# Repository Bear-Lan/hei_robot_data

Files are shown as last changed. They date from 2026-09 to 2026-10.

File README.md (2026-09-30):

<h1 align="center">HEI ReBot Lift</h1>

<p align="center">
  HEI ReBot Lift
</p>

<p align="center">
  <a href="README.md"><b>English</b></a> <b>|</b>
  <a href="README_zh.md"><b>中文</b></a> <b>|</b>
  <a href="README_Fr.md"><b>français</b></a> <b>|</b>
  <a href="README_es.md"><b>Español</b></a>
</p>

<p align="center">
  <a href="https://github.com/lipengdong/hei-rebot-lift/stargazers">
    
  </a>
</p>

## 🚀 Overview

**HEI ReBot Lift** is a **dual-arm lifting mobile robot project for embodied AI learning, reproduction, and real-robot validation**. Its goal is to **lower the barrier to building real robot learning systems**. It follows the idea of **truly reproducible open source**: not only releasing code, but also organizing **hardware materials, wiring, deployment steps, the VR teleoperation pipeline, dataset recording, ACT/VLA training, and real-robot rollout workflows**, so builders can move from hardware assembly all the way to policy deployment. The robot consists of dual arms, a lift platform, a four-wheel O-type omnidirectional chassis, and three cameras. The software is built on LeRobot and covers MuJoCo/Pinocchio inverse kinematics, LeRobotDataset, imitation learning, and VLA policy deployment.

<p align="center">
  <b>🚀 Dual-Arm Mobile Manipulation</b> · <b>📖 Open Hardware + Software Stack</b> · <b>🤖 LeRobot Ready</b>
</p>

<p align="center">
  <a href="#-quick-setup">🚀 Quick Setup</a> ·
  <a href="#-hardware">🦾 Hardware</a> ·
  <a href="#-startup-flow">🎮 Simulation / Teleoperation</a> ·
  <a href="#-record-data">📷 Record Data</a> ·
  <a href="#-train-act">🧠 Train ACT</a> ·
  <a href="#-train-smolvla">✨ Train VLA</a>
</p>

## ✨ Features

<div align="center">

<table>
  <thead>
    <tr>
      <th align="center">Icon</th>
      <th align="center">Capability</th>
      <th align="center">Description</th>
    </tr>
  </thead>
  <tbody>
    <tr><td align="center">🦾</td><td align="center">Dual-arm manipulation</td><td align="center">Damiao dual arms and grippers for teleoperation, recording, and policy rollout</td></tr>
    <tr><td align="center">⬆️</td><td align="center">Lift platform</td><td align="center">Automatic homing on startup, with the upper limit defined as <code>height.pos = 0</code></td></tr>
    <tr><td align="center">⭕</td><td align="center">Omnidirectional base</td><td align="center">Four-wheel O-type omnidirectional chassis with <code>x/y/theta</code> velocity control</td></tr>
    <tr><td align="center">🎮</td><td align="center">Keyboard / VR control</td><td align="center">Control the complete MuJoCo robot by keyboard or VR; Telegrip + Pinocchio/CasADi provide the VR IK pipeline</td></tr>
    <tr><td align="center">📷</td><td align="center">Three-camera data</td><td align="center"><code>front</code>, <code>left_wrist</code>, and <code>right_wrist</code> visual inputs</td></tr>
    <tr><td align="center">🧠</td><td align="center">Imitation learning / VLA</td><td align="center">Record keyboard/VR simulation data, visualize LeRobotDataset episodes, train ACT/VLA policies, and run them in simulation or on hardware</td></tr>
  </tbody>
</table>

HEI ReBot Lift demo

</div>

## 🤝 Get Your Own Robot / Join the Community

If you want to reproduce your own **HEI ReBot Lift**, you can follow the hardware materials, BOM, wiring notes, and software deployment documents gradually organized in this project to source parts and build the robot yourself. We also welcome builders and researchers interested in dual-arm mobile manipulation, VR teleoperation, LeRobot data collection, ACT/VLA training, and real-robot deployment to exchange ideas with us.

If you want to **get your own robot faster**, or would like to collaborate on hardware reproduction, teaching labs, data collection, algorithm validation, or application deployment, feel free to contact us.

<p align="center">
  <b>WeChat community / collaboration:</b> <code>hgm159951</code> &nbsp;&nbsp;|&nbsp;&nbsp;
  <b>Email:</b> <a href="mailto:hgm159951@163.com">hgm159951@163.com</a>
</p>

Reproductions, discussions, issues, improvements, and real-robot test feedback are all welcome.

## 📁 Project Layout

```text
hei-rebot-lift/
├── README.md
├── README_zh.md
├── README_Fr.md
├── README_es.md
├── LICENSE
├── community/                    # Community notes and collaboration records
├── hardware/                     # Hardware BOM, wiring, device binding, mechanical materials
├── media/                        # Images, videos, and README assets
├── docs/                         # Deployment and usage documentation
└── software/
    └── lerobot-hei-rebot-lift/   # Runnable LeRobot-based software project
```

The runnable software lives in:

```text
software/lerobot-hei-rebot-lift/
```

Quick Setup starts at the repository root. For later sections, open a new
terminal at the repository root for each command block; each block includes its
own `cd`. Replace `192.168.31.127` with your robot IP. The headset connects to
the **computer IP**, not the robot IP. The software directory is:

```bash
cd software/lerobot-hei-rebot-lift
```

## 🖼️ Showcase

<p align="center">
  HEI ReBot Lift robot
</p>

## ⭐ Star History

<p align="center">
  <a href="https://www.star-history.com/?repos=lipengdong%2Fhei-rebot-lift&type=date&legend=top-left">
    HEI ReBot Lift Star History
  </a>
</p>

## 🗺️ Roadmap & Latest Status

We will continue improving HEI ReBot Lift across hardware materials, software interfaces, data collection workflows, and mainstream embodied AI policy integrations. The table below summarizes the current status and links to the related documentation.

| Module | Status | Current Progress | Related DOC |
| --- | --- | --- | --- |
| Robot body | ✅ First version completed | Dual arms, lift platform, and four-wheel O-type omnidirectional base are integrated and tested as a complete system | [Hardware](hardware/README.md) |
| Complete robot URDF | ✅ Completed | Full robot model includes the chassis, wheels, lift, dual arms, parallel grippers, and TCP frames for simulation and real-robot IK | [URDF Model](software/lerobot-hei-rebot-lift/examples/hei_rebot_lift/VR_mujoco_ik/mujoco_ik/model/HEI_robot_urdf/) |
| MuJoCo simulation testing | ✅ Completed | Keyboard and VR control of both arms, grippers, lift, and chassis have been tested; includes wheel animations, workspace projection, and stable-grasp pick-and-place demonstrations | [Simulation Guide](software/lerobot-hei-rebot-lift/examples/hei_rebot_lift/VR_mujoco_ik/README.md) |
| Simulation data and policy loop | ✅ Verified | Keyboard or VR demonstrations publish synchronized 18-D states/actions and three camera views for LeRobotDataset recording, visualization, ACT training, and MuJoCo policy rollout | [Dataset, Training & Inference Guide](software/lerobot-hei-rebot-lift/examples/hei_rebot_lift/VR_mujoco_ik/mujoco_ik/SIM_DATASET_WORKFLOW.md) |
| Damiao motor driver | ✅ First version completed | `damiao_u2can` is implemented for dual arms, grippers, chassis, and lift motor control | [Damiao U2CAN](software/lerobot-hei-rebot-lift/src/lerobot/motors/damiao_u2can/) |
| Lift platform | ✅ First version completed | Supports upper-limit homing on startup and `height.pos` position-target control | [Robot Driver](software/lerobot-hei-rebot-lift/src/lerobot/robots/hei_rebot_lift/README.md) · [Independent Lift Control](software/lerobot-hei-rebot-lift/examples/hei_rebot_lift/README.md#independent-lift-test) |
| Omnidirectional base | ✅ First version completed | Supports `x.vel`, `y.vel`, and `theta.vel` commands with basic acceleration smoothing | [Robot Driver](software/lerobot-hei-rebot-lift/src/lerobot/robots/hei_rebot_lift/README.md) · [Independent Chassis Control](software/lerobot-hei-rebot-lift/examples/hei_rebot_lift/README.md#independent-chassis-test) |
| Three-camera vision | ✅ First version completed | Supports `front`, `left_wrist`, and `right_wrist` OpenCV cameras with MJPG by default | [Robot Driver](software/lerobot-hei-rebot-lift/src/lerobot/robots/hei_rebot_lift/README.md) |
| VR + MuJoCo IK | ✅ First version completed | Telegrip + MuJoCo + Pinocchio/CasADi is connected to the real-robot control pipeline | [VR MuJoCo IK](software/lerobot-hei-rebot-lift/examples/hei_rebot_lift/VR_mujoco_ik/README.md) |
| LeRobot integration | ✅ First version completed | `hei_rebot_lift` robot/client/host is implemented with teleoperate, record, replay, evaluate, and rollout scripts | [Examples](software/lerobot-hei-rebot-lift/examples/hei_rebot_lift/README.md) |
| Real-robot data collection | ✅ First version completed | Supports LeRobotDataset recording, resume recording, visualization, and bad-episode cleanup | [Record Guide](software/lerobot-hei-rebot-lift/examples/hei_rebot_lift/README.md) |
| ACT training and rollout | ✅ Verified | Supports ACT training and real-robot rollout | [Examples](software/lerobot-hei-rebot-lift/examples/hei_rebot_lift/README.md) |
| SmolVLA / VLA | ✅ Initial support | Supports SmolVLA training and real-robot rollout entry points | [Examples](software/lerobot-hei-rebot-lift/examples/hei_rebot_lift/README.md) |
| Open hardware materials | ✅ Completed | Overall BOM, full robot STEP assembly, printed-part STL files, metal parts list, and STEP/DWG manufacturing files are available | [Hardware](hardware/README.md) |
| Community and reproduction | 🚧 Ongoing | WeChat group, email contact, and GitHub project entry are available | [Community](community/README.md) |
| Other mainstream VLA deployment reproduction | ⏳ Coming soon | Plan to reproduce and test more mainstream VLA policies for training, inference, and real-robot deployment on HEI ReBot Lift | Not completed |

## 🦾 Hardware

The hardware package now includes the overall BOM, full robot STEP assembly, 3D printed parts, and metal/CNC/sheet-metal manufacturing files.

| Resource | File / Directory | Description |
| --- | --- | --- |
| Hardware guide | [hardware/README.md](hardware/README.md) | Hardware directory index, reproduction order, and safety checklist |
| Overall BOM V1.1 | [hardware/HEI_ReBot_Lift_BOM.md](hardware/HEI_ReBot_Lift_BOM.md) / [xlsx](hardware/HEI_ReBot_Lift_BOM.xlsx) | Main purchasing and preparation checklist; verify current prices before purchase |
| Full robot assembly | [hardware/Hei_robot_lift.STEP](hardware/Hei_robot_lift.STEP) | Full STEP model for structure review and assembly reference |
| 3D printed parts | [hardware/3D_Printed_Parts/](hardware/3D_Printed_Parts/) | STL files for printed covers, brackets, lift, chassis, and camera-related parts |
| Metal body parts list | [hardware/Metal_Parts/HEI_Metal_Body_Parts_List.xlsx](hardware/Metal_Parts/HEI_Metal_Body_Parts_List.xlsx) | Metal/CNC/sheet-metal part list |
| Metal CAD files | [hardware/Metal_Parts/step/](hardware/Metal_Parts/step/) / [hardware/Metal_Parts/dwg/](hardware/Metal_Parts/dwg/) | STEP and DWG files for machining communication |

### Assembly and Debugging Tutorial

Scan the QR code for the HEI ReBot Lift assembly and debugging tutorial. Use it
together with the repository BOM, latest CAD files, and safety checklist.

<p align="center">
  <a href="media/hei-rebot-lift-assembly-debugging-tutorial.png">HEI ReBot Lift assembly and debugging tutorial QR code</a>
  <br>
  <em>Scan to open the assembly and debugging tutorial.</em>
</p>

```text
Dual arms: left and right arms with 7 Damiao motors each. Joints 1-3 use DM4340P, joints 4-6 and gripper use DM4310
Chassis: four-wheel O-type omnidirectional mobile base, using DM4310 wheel motors
Lift: lead-screw lift platform using a DM4310 motor. On startup, the upper limit is homed as height.pos = 0
Cameras: three OpenCV cameras: front, left_wrist, right_wrist
Communication: ZMQ between robot-side host and computer-side client
Teleoperation: VR headset and controllers. Telegrip captures VR data; MuJoCo + Pinocchio/CasADi compute IK
```

## 🧩 Software Modules

```text
software/lerobot-hei-rebot-lift/src/lerobot/robots/hei_rebot_lift/        Robot driver
software/lerobot-hei-rebot-lift/src/lerobot/motors/damiao_u2can/          Damiao U2CAN communication
software/lerobot-hei-rebot-lift/examples/hei_rebot_lift/                  Record, replay, evaluate, and rollout scripts
software/lerobot-hei-rebot-lift/examples/hei_rebot_lift/VR_mujoco_ik/     VR + MuJoCo + Pinocchio IK
```

## ⚡ Quick Setup

Both machines need this project's code, but their dependencies and roles differ.
**Start each subsection at the repository root on the specified machine. Do not
execute robot-side and computer-side steps consecutively on one machine.**

| Machine | Environment | Purpose |
| --- | --- | --- |
| Robot-side Jetson | `lerobot5` | Hardware drivers, serial binding, robot host; no VR/IK environment needed |
| Your computer: control/training | `lerobot5` | Teleoperation client, dataset recording/editing, visualization, training, policy inference |
| Your computer: VR/simulation | `hei-rebot-vr` | Telegrip, MuJoCo, Pinocchio/CasADi FK/IK |

### 1. Robot-Side Jetson Installation

**Run only on the robot.** Install the hardware extras without the computer-side
dataset visualization and training extras. This still includes the project's
base dependencies; it is not a standalone driver package without PyTorch.

```bash
cd software/lerobot-hei-rebot-lift
conda create -n lerobot5 python=3.12 -y
conda activate lerobot5
python -m pip install -e ".[hardware,pyzmq-dep]"
python -c "import serial, zmq, cv2; print('robot dependencies ok')"
```

If a working `lerobot5` environment already exists, skip creation and activate
it before installation. For Jetson PyTorch/torchvision platform or version
conflicts, account for the installed JetPack and this project's version
constraints. Do not copy desktop CUDA wheels or bypass all dependencies with
`--no-deps`.

Next, follow Device Mapping below, verify limit switches and cameras, then start
`hei-rebot-lift-host` using Startup Flow. Do not create `hei-rebot-vr` on the robot.

### 2. Your Computer: Control, Recording, and Training

**Run only on your computer.** This environment runs `teleoperate.py`,
`record.py`, training, replay, and policy inference; it does not directly open
the robot's motor serial ports.

```bash
cd software/lerobot-hei-rebot-lift
conda create -n lerobot5 python=3.12 -y
conda activate lerobot5
python -m pip install -e ".[core_scripts,training,pyzmq-dep]"
python -m pip show pyzmq rerun-sdk pynput datasets accelerate
```

This includes dataset recording/editing, Rerun visualization, keyboard input,
ZMQ, and general training dependencies. Install SmolVLA-specific dependencies
in its training section below. Skip creation if `lerobot5` already exists.

### 3. Your Computer: VR/MuJoCo IK

On your computer, **open another terminal at the repository root**. Telegrip and
MuJoCo IK share `hei-rebot-vr`; do not mix these dependencies into `lerobot5`.
Use the conda-forge versions in `environment.yml` for FK/IK; do not separately
install `pin` with pip.

```bash
cd software/lerobot-hei-rebot-lift/examples/hei_rebot_lift/VR_mujoco_ik
conda env create -f environment.yml
conda activate hei-rebot-vr
env -u LD_LIBRARY_PATH python -c "import pinocchio as pin; from pinocchio import casadi as cpin; print(pin.__version__); print('casadi binding ok')"
```

For an existing environment, replace creation with
`conda env update -n hei-rebot-vr -f environment.yml --prune`. Launch wrappers
activate it automatically. Test pure simulation before connecting real hardware;
see the [VR deployment guide](software/lerobot-hei-rebot-lift/examples/hei_rebot_lift/VR_mujoco_ik/README.md).

## 🔌 Device Mapping

Stable udev device names are used by default:

```text
/dev/hei_right_arm   Right arm U2CAN
/dev/hei_left_arm    Left arm U2CAN
/dev/hei_chassis     Chassis U2CAN
/dev/hei_lift        Lift motor U2CAN
/dev/hei_lift_io     Lift limit-switch serial port
```

### 1. Serial and Camera Discovery and Binding Wizard

Run [Port_Binding_Wizard.py](software/lerobot-hei-rebot-lift/examples/hei_rebot_lift/debug/Port_Binding_Wizard.py)
on the **robot-side Jetson**. It identifies serial adapters from responding motor
IDs and limit-switch IO frames, then previews each camera so the user can assign
front, left-wrist, right-wrist, or skip it. Missing cameras do not stop available
devices from being bound. It does not enable motors, write zeros, or command motion.

**Prepare the hardware:**

1. Stop `hei-rebot-lift-host` and all motor/serial debug programs so the ports are free.
2. Power down and support the arms before changing wiring. Temporarily disconnect **right-arm IDs 4-7**, leaving IDs 1-3 connected; keep the left arm fully connected on IDs 1-7.
3. Check chassis IDs 1-4, lift ID 1, and the lift limit-switch IO wiring. Power the four U2CAN boards, IO board, and motors needed for discovery.
4. Keep USB sockets unchanged throughout scanning and rule installation.

Set serial-port read/write permissions before running the Python wizard:

```bash
sudo chmod 666 /dev/ttyACM*
sudo chmod 666 /dev/ttyUSB*
```

Start the interactive wizard from the repository root:

```bash
cd software/lerobot-hei-rebot-lift
PYTHONPATH=src conda run --no-capture-output -n lerobot5 \
  python -u examples/hei_rebot_lift/debug/Port_Binding_Wizard.py
```

Review the scan, confirm the arm/chassis/lift/IO mapping, and choose whether to
install the system rules. The default output is
`examples/hei_rebot_lift/rules/99-nx-robot.rules`, with an existing-file backup.
Installation into `/etc/udev/rules.d/` requires `sudo`; the wizard reloads rules
and checks symlinks. Existing lidar and IMU rules are preserved; those devices
are not identified by this scan.

**Verify the bindings:**

```bash
ls -l /dev/hei_right_arm /dev/hei_left_arm /dev/hei_chassis /dev/hei_lift /dev/hei_lift_io
ls -l /dev/hei_front_camera /dev/hei_left_wrist_camera /dev/hei_right_wrist_camera
```

If a symlink is missing, reconnect that USB device to the same socket and check
again. After verification, power down, reconnect right-arm IDs 4-7, and power up
before independent hardware tests below. Rules follow physical USB topology: keep each adapter
in its original socket, and rebind after changing sockets or hubs.

For missing/ambiguous devices, busy ports, or invalid IO frames, check power,
USB/CAN wiring, motor IDs, competing processes, and the IO baud rate before
accepting any mapping. For permission errors, check serial access (usually the
`dialout` group). Use interactive mode for first deployment. `--yes --install`
skips camera preview and preserves existing camera rules; use `--skip-cameras`
when rebinding serial devices only.

### 2. After Binding: Arm Zeros and Independent Hardware Tests

**Run all tests on the robot-side Jetson; no VR or computer client is needed.**
Run one debug tool at a time with the host and other serial programs stopped.
Each block starts in a new terminal at the repository root. For keyboard tools,
activate `lerobot5` and run Python directly in an interactive terminal; allocate
a TTY for SSH (for example, `ssh -t USER@ROBOT_IP`). Dashboards refresh in place.
Keep the physical emergency stop reachable; software stop keys do not replace it.

#### 2.1 Position the Arm at Its Designed Mechanical Zero Before Writing

**Warning: `Arm_Zero_Status_Test.py` immediately disables and writes zeros to
all seven motors (IDs 1-7) on that arm. It has no confirmation or read-only mode.
Do not start it at an arbitrary pose or use it for routine status inspection.**
Support the arms before disabling motors, as they can fall under gravity.

Use the assembly design and joint-zero definitions in the
[complete URDF model](software/lerobot-hei-rebot-lift/examples/hei_rebot_lift/VR_mujoco_ik/mujoco_ik/model/HEI_robot_urdf/)
to position the arm at its mechanical zero, not the VR controller's default
working pose. The physical gripper zero is closed (`0 rad`); do not force it
against its stop. The script cannot verify the pose. If the designed zero is
unclear, check the assembly references before writing anything.

<p align="center">
  <a href="media/arm_zero.png">Designed mechanical zero posture of both arms</a>
  <br>
  <em>Designed mechanical zero posture reference. Verify each joint against the assembly design before writing zeros; this is not the VR working pose.</em>
</p>

Write the right-arm zeros:

```bash
cd software/lerobot-hei-rebot-lift
conda activate lerobot5
PYTHONPATH=src python -u examples/hei_rebot_lift/debug/Arm_Zero_Status_Test.py \
  --port /dev/hei_right_arm
```

Exit with `Ctrl+C`, correctly position the left arm, and then run:

```bash
cd software/lerobot-hei-rebot-lift
conda activate lerobot5
PYTHONPATH=src python -u examples/hei_rebot_lift/debug/Arm_Zero_Status_Test.py \
  --port /dev/hei_left_arm
```

The script keeps motors disabled after writing and refreshes
`POS/VEL/TORQUE/ERROR`. Verify all seven motors are connected and responding
before checking positions near zero. A displayed zero alone does not establish
connectivity or successful calibration. Interpret `ERROR` according to the motor
protocol; not every nonzero state is a fault. Exit after calibration; rewrite
zeros only when assembly or maintenance requires recalibration.

#### 2.2 Independent Chassis Test: Directions, Gears, and Wheel Feedback

Secure the chassis with wheels off the ground, clear of cables and people.
This tool connects only the chassis, not the arms, lift, or cameras.
**All four wheels move through chassis kinematics; this is not single-wheel jog.**

```bash
cd software/lerobot-hei-rebot-lift
conda activate lerobot5
PYTHONPATH=src python -u examples/hei_rebot_lift/debug/Chassis_Status_Test.py \
  --port /dev/hei_chassis
```

| Key | Function |
| --- | --- |
| `1 / 2 / 3` | Low / medium / high gear; begin with low gear `1` |
| `W / S` | Forward / backward |
| `A / D` | Strafe left / right |
| `Q / E` | Rotate left / right |
| `Space` | Software command for zero speed on all wheels |
| `X` or `Ctrl+C` | Exit and stop the chassis |

Hold or repeat a direction key to maintain motion; the default key watchdog
clears the request after `0.65 s` without another direction event. Test each
direction briefly while observing requested/reconstructed body velocity and
each wheel's target/measured angular velocity, position, torque, and state code.
Body velocities use driver command units, not directly measured meters/second.

| Motor ID | Wheel position | Dashboard label |
| --- | --- | --- |
| `1` | Right front | `RF` |
| `2` | Right rear | `RR` |
| `3` | Left rear | `LR` |
| `4` | Left front | `LF` |

Stop for a stationary wheel, incorrect mapping, missing feedback, or abnormal
shaking; check IDs, wiring, and configuration rather than increasing speed.
After the suspended test passes, verify physical directions at low gear in a
clear area. Single-wheel jogging needs a separate mode not provided by this
tool; never substitute the arm zero-writing script on the chassis port.

#### 2.3 Independent Lift Test: Homing, Height, and Limit IO

**Startup automatically homes upward.** Check both limit-switch connections and
clear the travel path first. Support structures that could fall when disabled
and keep the emergency stop ready. This tool reuses production lift logic and
opens only the lift motor and limit IO ports.

```bash
cd software/lerobot-hei-rebot-lift
conda activate lerobot5
PYTHONPATH=src python -u examples/hei_rebot_lift/debug/Lift_Status_Test.py \
  --motor-port /dev/hei_lift --io-port /dev/hei_lift_io --height-step-mm 2
```

| Key | Function |
| --- | --- |
| `I / K` | Raise / lower target height; this example changes it by `2 mm` per key event |
| `Space` | Stop and use current reported height as the hold target |
| `H` | Home upward again, only with a safe travel path |
| `X` or `Ctrl+C` | Exit, stop, and disable |

Upper-limit homing defines `0 mm`; downward heights are negative, within
`-800..0 mm`. Move down and up in small steps while checking current/target
height, error, measured speed, motor command speed, IO freshness, and limits.
Confirm the relevant IO state at a known limit. Stop for offline IO, both limits
active, or incorrect states; investigate before retrying rather than repeatedly
driving into end stops.

**Finish all independent tests and exit the debug tools** before the simulation
practice and real startup below. Never let a debug tool compete with the host
for a serial port.

### 3. Camera Mapping

Default cameras (verify actual devices on the **robot**, not your computer):

```text
front       /dev/hei_front_camera
left_wrist  /dev/hei_left_wrist_camera
right_wrist /dev/hei_right_wrist_camera
```

Find connected cameras:

```bash
cd software/lerobot-hei-rebot-lift
PYTHONPATH=src conda run --no-capture-output -n lerobot5 \
  lerobot-find-cameras opencv --opencv-fourcc MJPG --opencv-width 640 --opencv-height 480 --opencv-fps 30
```

### Stable Camera Mapping

The binding wizard above creates stable `/dev/hei_*_camera` symlinks, so camera
IDs normally require no further edits. Run the wizard again after moving a
camera to another physical USB socket.

To manually override a camera device ID or path, edit
`software/lerobot-hei-rebot-lift/src/lerobot/robots/hei_rebot_lift/config_hei_rebot_lift.py`,
then change the corresponding `index_or_path` in `hei_rebot_lift_cameras_config()`:

```python
def hei_rebot_lift_cameras_config() -> dict[str, CameraConfig]:
    return {
        "front": OpenCVCameraConfig(index_or_path="/dev/hei_front_camera", fps=30, width=640, height=480, fourcc="MJPG"),
        "left_wrist": OpenCVCameraConfig(index_or_path="/dev/hei_left_wrist_camera", fps=30, width=640, height=480, fourcc="MJPG"),
        "right_wrist": OpenCVCameraConfig(index_or_path="/dev/hei_right_wrist_camera", fps=30, width=640, height=480, fourcc="MJPG"),
    }
```

Keep the names `front`, `left_wrist`, and `right_wrist` unchanged: datasets,
policies, and clients use these keys. Do not edit `camera_opencv.py` or the VR
YAML for USB IDs. A separate client keeps the same camera keys and dimensions;
the robot host opens the physical USB devices.

## 🎮 Startup Flow

### Identify the Computer and Robot IPs First

The examples use your computer IP `192.168.31.245` and example robot IP
`192.168.31.127`. **If the robot address differs, replace robot addresses only;
do not replace the computer address used by the headset.**

| Address | Owner | Used for |
| --- | --- | --- |
| `192.168.31.245` | Your control computer running Telegrip and MuJoCo IK | Headset browser: `https://192.168.31.245:8443` |
| `192.168.31.127` | Robot Jetson running the host | Client: `--remote-ip 192.168.31.127`; VR camera endpoint: `tcp://192.168.31.127:6556` |
| `localhost` / `127.0.0.1` | The machine running that program, not the remote robot | Local VR, action, and feedback connections when Telegrip, MuJoCo IK, and the client share one computer |

Practice in pure simulation below before real control. Keyboard simulation only
needs the computer; VR simulation needs the computer and headset to communicate. For real control, also connect the
robot to the same mutually reachable LAN. **Run each block in a new terminal at
the repository root on the specified machine.** Keep long-running processes open.

### 1. Beginner Practice: Computer-Side Pure Simulation (No Hardware)

<p align="center">
  HEI ReBot Lift VR simulation in MuJoCo
</p>

Install `hei-rebot-vr` first. **Do not start the robot host, `teleoperate.py`,
`record.py`, or the real bridge during practice; stop them if already running.**
Pure simulation requires no motors, device bindings, or robot feedback and does
not publish real actions on `6558`.

#### 1.1 Practice by Keyboard Without a Headset

```bash
cd software/lerobot-hei-rebot-lift/examples/hei_rebot_lift/VR_mujoco_ik
./run_hei_robot_keyboard_sim.sh
```

Press `1/2/3/4` to select chassis, lift, left arm, or right arm. Chassis uses
`W/S`, `A/D`, and `Q/E`; lift uses `I/K`; arm TCP translation uses `W/S`,
`A/D`, and `R/F`, while rotation uses `U/J`, `I/K`, and `O/L`. Use `Z/X` to
open/close the selected gripper, and `5/6` to reset the left/right arm gradually. See the
[keyboard and VR simulation guide](software/lerobot-hei-rebot-lift/examples/hei_rebot_lift/VR_mujoco_ik/README.md)
for all controls and speed options.

#### 1.2 Computer VR Practice Terminal A: Start Telegrip

```bash
cd software/lerobot-hei-rebot-lift/examples/hei_rebot_lift/VR_mujoco_ik
./run_telegrip.sh
```

Connect the headset and computer to the same LAN. In the headset browser, open
`https://192.168.31.245:8443` (computer IP), verify the self-signed certificate
warning, and enter VR.

#### 1.3 Computer VR Practice Terminal B: Start the Complete Robot Simulation

```bash
cd software/lerobot-hei-rebot-lift/examples/hei_rebot_lift/VR_mujoco_ik
./run_hei_robot_vr_sim.sh
```

Observe the robot in the **MuJoCo window on your computer**. The scene includes
both arms, parallel grippers, lift, four-wheel omnidirectional chassis, a table,
cubes, and a banana for pick-and-place practice. Without a physical robot, no
real camera feed will appear in the headset; simulation still works.
`vr_images.enabled` is currently `false` in `telegrip/config.yaml`; leave it
disabled for practice. Changing it requires restarting Telegrip.

#### 1.4 Practice Controller Inputs in Order

<table align="center">
  <tr>
    <td align="center"><a href="media/META-QUEST-BUTTON.jpg">Meta Quest system button on the right controller</a><br><b>Meta Quest System Button</b></td>
    <td align="center"><a href="media/META-GRIP-BUTTON.jpg">Side grip button location</a><br><b>Grip: Side Button</b></td>
    <td align="center"><a href="media/META-FRONT-TRIGGER.jpg">Front trigger location</a><br><b>Trigger: Front Trigger</b></td>
  </tr>
</table>

Click an image to view it at full size.

> [!IMPORTANT]
> **Calibrate the VR origin before control: hold the right controller's META QUEST BUTTON for about 3 seconds to recenter using the headset's current position and heading as the VR reference origin for this session.**
> **Recalibrate after changing your standing/seated position or operating direction. If controller motion and arm motion point in different directions or directional tracking feels wrong, stop control and recalibrate before continuing.**
> Sequence: **release both `grip` buttons → center the sticks → face the intended forward direction from your new position → hold the Meta Quest button for about 3 seconds → let tracking settle and hold `grip` again**. Verify direction with a small movement first.

The Meta Quest button recenters the **headset/VR reference frame**; `grip`
captures each arm's relative control origin. These are different operations.
Neither writes motor zeros nor replaces lift homing. Follow the calibration
procedure for both simulated and real VR control.

| Exercise | Procedure |
| --- | --- |
| Single-arm translation and rotation | Hold that side's `grip` to capture a relative origin; make small XYZ translations and rotations while observing the TCP. Practice each arm separately |
| Release and recapture the origin | Release `grip` to stop tracking, reposition the controller comfortably, then hold it again; the arm need not follow the controller back to its origin |
| Gripper pick and place | Simulation grippers start closed; real startup restores measured state. While holding `grip`, press `trigger` to open and release it to close; close near an object for stable-grasp practice, then open to place it |
| Lift | Left `grip` + left stick vertical; releasing left `grip` stops the lift request |
| Chassis | Right `grip` + right stick for forward/backward and strafing; right `B` rotates clockwise, left `Y` counterclockwise; releasing right `grip` stops the request |
| Reset | With the corresponding `grip` released, right `A` / left `X` gradually resets that arm. Focus the computer's MuJoCo window and press `R` to reset the robot and objects, in pure simulation only |

Keep sticks centered when practicing arm motion to avoid unintended chassis or
lift movement. At joint/workspace boundaries, reduce motion and return to the
reachable area instead of pushing farther out. See the
[controller tutorial](software/lerobot-hei-rebot-lift/examples/hei_rebot_lift/VR_mujoco_ik/README.md)
for complete instructions.

#### 1.5 Collect, Train, and Run Policies in Simulation

The complete MuJoCo environment is also a reproducible policy-development
environment. Demonstrations can be controlled by **keyboard or VR**, recorded
with the same 18-D state/action schema and `front`, `left_wrist`, and
`right_wrist` camera keys used by the robot, then visualized, trained, and
played back through a policy in MuJoCo.

| Stage | MuJoCo process (`hei-rebot-vr`) | LeRobot process (`lerobot5`) |
| --- | --- | --- |
| Keyboard demonstration | `run_hei_robot_keyboard_dataset_sim.sh` | `run_hei_robot_keyboard_record.sh` |
| VR demonstration | Telegrip + `run_hei_robot_vr_dataset_sim.sh` | `run_hei_robot_mujoco_record.sh` |
| Dataset inspection | - | `lerobot-dataset-viz` or `inspect_mujoco_dataset.py` |
| Policy training | - | `lerobot-train` with ACT or another supported policy |
| Simulation inference | `run_hei_robot_policy_sim.sh` | `run_hei_robot_mujoco_rollout.sh` |

The ordinary `run_hei_robot_keyboard_sim.sh` and `run_hei_robot_vr_sim.sh`
commands are practice-only and do not publish dataset samples. Recording uses
the dedicated `*_dataset_sim.sh` server plus its recorder in a second terminal.
Keep the simulation and recording FPS equal.

Follow the **[MuJoCo Dataset, Training, and Inference Guide](software/lerobot-hei-rebot-lift/examples/hei_rebot_lift/VR_mujoco_ik/mujoco_ik/SIM_DATASET_WORKFLOW.md)**
for exact environment boundaries, launch commands, keyboard/VR recording,
episode visualization, ACT training, and policy rollout. This workflow never
connects to the physical robot unless you separately start the real-robot
programs.

#### 1.6 Move to Hardware Only After Practice

- Control each arm's translation/rotation and confidently release/recapture the relative origin with `grip`.
- Recenter with the Meta Quest button and know to recalibrate after moving, changing heading, or observing a direction mismatch.
- Complete a pick-and-place exercise and understand that gripper state persists after releasing `grip`.
- Control chassis/lift directions, stop their requests, and keep sticks centered.
- Distinguish simulation and real launch scripts, locate the emergency stop, and understand real workspace hazards.

Close the pure-simulation viewer or stop it with `Ctrl+C`, then follow sections
2 and 3 below. Telegrip may stay running. If camera streaming was disabled,
restore `vr_images.enabled: true`, check the robot camera IP, and restart
Telegrip when real camera display is needed; do not launch duplicate instances.
**Simulation practice does not replace hardware safety checks.** Stable grasping
is a kinematic demonstration, not contact-physics validation. Motor directions,
zeros, limits, and load capacity still require independent verification, and
simulation lift speed can differ from real hardware.

### 2. Robot-Side Jetson: Start the Host (Terminal 1)

Run only on the robot. Complete device mapping, clear the workspace, and keep
the emergency stop reachable. Startup moves the lift upward to home;
**wait for homing to finish** before proceeding. The host runs on the robot;
it does not need the computer IP and is not the computer-side client.

```bash
cd software/lerobot-hei-rebot-lift
PYTHONPATH=src conda run --no-capture-output -n lerobot5 hei-rebot-lift-host
```

Keep this robot terminal running. Do not start Telegrip or MuJoCo IK on Jetson.

### 3. Your Computer: Start the Control Programs

Run all three programs below on **your computer** at `192.168.31.245`, not on Jetson.

#### 3.1 Start Telegrip (Computer Terminal 2)

```bash
cd software/lerobot-hei-rebot-lift/examples/hei_rebot_lift/VR_mujoco_ik
./run_telegrip.sh
```

#### 3.2 Headset Browser: Open the Computer's Page

For example, if the computer running Telegrip has LAN IP `192.168.31.245`, enter
this address in the **VR headset browser**:

```text
https://192.168.31.245:8443
```

Connect the headset and computer to the same LAN and start `run_telegrip.sh`
before opening the page. Use the **computer IP, not the robot IP**, and use
`https`. On the first visit, verify that the address belongs to your computer
before continuing past the self-signed certificate warning, then enter VR using
the page controls.

VR camera display is currently disabled. To enable it, set
`vr_images.enabled: true` and
`vr_images.endpoint: tcp://192.168.31.127:6556` in the computer's
`software/lerobot-hei-rebot-lift/examples/hei_rebot_lift/VR_mujoco_ik/telegrip/config.yaml`.
This must use the **robot IP**. Restart Telegrip after editing it; the client's
`--remote-ip` does not update this configuration.

#### 3.3 Start the Teleoperation Client (Computer Terminal 3)

Set `--remote-ip` to the **robot Jetson IP**, not the computer's `192.168.31.245`.
The client supplies robot feedback and waits for MuJoCo IK actions:

```bash
cd software/lerobot-hei-rebot-lift
PYTHONPATH=src conda run --no-capture-output -n lerobot5 python -u examples/hei_rebot_lift/teleoperate.py --remote-ip 192.168.31.127
```

#### 3.4 Start the Complete-Model Real Bridge (Computer Terminal 4)

Run on the same computer as Telegrip and the client. Default internal
connections stay local; do not replace their addresses with the robot IP:

```bash
cd software/lerobot-hei-rebot-lift/examples/hei_rebot_lift/VR_mujoco_ik
./run_hei_robot_vr_real.sh --enable-real-publish
```

With fresh robot feedback and VR data, release both grip buttons together and
wait for `command bridge ARMED`. The flag acknowledges real command publishing;
it does not bypass synchronization. For simulation only, use
`./run_hei_robot_vr_sim.sh`; the legacy dual-arm entry is `./run_mujoco_ik.sh`.
See the [VR guide](software/lerobot-hei-rebot-lift/examples/hei_rebot_lift/VR_mujoco_ik/README.md)
for controller inputs, recovery, and lift visualization limitations.

Keep **one robot-side host and three computer-side programs** running. To record
data, replace `teleoperate.py` in computer terminal 3 with `record.py`; never run
both together.

## 📷 Record Data

Stop `teleoperate.py` first. `record.py` replaces it as the action receiver and
feedback publisher; never run both together. Keep the host and Telegrip running,
then release both grips to re-arm the bridge after feedback reconnects.

```bash
cd software/lerobot-hei-rebot-lift
PYTHONPATH=src conda run --no-capture-output -n lerobot5 python -u examples/hei_rebot_lift/record.py   --repo-id HGM/hei_rebot_lift_task1   --remote-ip 192.168.31.127   --num-episodes 5   --episode-time-sec 120   --reset-time-sec 30   --task-description "Pick up the yellow block from the floor and put it on the table in front"
```

By default, data is saved locally and is not pushed to the Hugging Face Hub. Add `--push-to-hub` when uploading is needed.

## 🧠 Train ACT

Train on your computer; no robot host or VR process is required. Use the actual
dataset path printed during recording. If you chose a custom `--root`, also pass
`--dataset.root=YOUR_DATASET_PATH`; the dataset ID must match. These short runs
are smoke tests, not a guarantee of a deployable policy.

```bash
cd software/lerobot-hei-rebot-lift
PYTHONPATH=src conda run --no-capture-output -n lerobot5 lerobot-train   --dataset.repo_id=HGM/hei_rebot_lift_task1   --policy.type=act   --policy.device=cuda   --policy.push_to_hub=false   --output_dir=outputs/train/act_hei_rebot_lift_task1   --job_name=act_hei_rebot_lift_task1   --batch_size=8   --steps=10000   --save_freq=10000   --log_freq=200   --num_workers=4   --wandb.enable=false
```

## ✨ Train SmolVLA

Install the policy-specific dependencies first (new terminal at repository root):

```bash
cd software/lerobot-hei-rebot-lift
conda run --no-capture-output -n lerobot5 python -m pip install -e ".[smolvla]"
```

The general `training` extra does not install every VLA policy's dependencies.

```bash
cd software/lerobot-hei-rebot-lift
PYTHONPATH=src conda run --no-capture-output -n lerobot5 lerobot-train   --dataset.repo_id=HGM/hei_rebot_lift_task1   --policy.type=smolvla   --policy.device=cuda   --policy.push_to_hub=false   --output_dir=outputs/train/smolvla_hei_rebot_lift_task1   --job_name=smolvla_hei_rebot_lift_task1   --batch_size=1   --steps=1000   --save_freq=1000   --log_freq=50   --num_workers=2   --wandb.enable=false
```

## 🤖 Real-Robot Rollout

Keep the robot host running, but stop VR command publishing and any teleoperation,
recording, or replay process first. Use only one robot command source. Confirm the
checkpoint exists and camera names match the training data; start with a clear
workspace and a short test.

ACT rollout:

```bash
cd software/lerobot-hei-rebot-lift
PYTHONPATH=src conda run --no-capture-output -n lerobot5 python -u examples/hei_rebot_lift/rollout.py   --remote-ip 192.168.31.127   --model-id outputs/train/act_hei_rebot_lift_task1/checkpoints/010000/pretrained_model   --task "Pick up the yellow block from the floor and put it on the table in front"   --duration-sec 30   --inference sync
```

SmolVLA rollout:

```bash
cd software/lerobot-hei-rebot-lift
PYTHONPATH=src conda run --no-capture-output -n lerobot5 python -u examples/hei_rebot_lift/rollout.py   --remote-ip 192.168.31.127   --model-id outputs/train/smolvla_hei_rebot_lift_task1/checkpoints/001000/pretrained_model   --task "Pick up the yellow block from the floor and put it on the table in front"   --duration-sec 60   --fps 10   --inference rtc
```

## 📖 More Documentation

- [Documentation index](docs/README.md)
- [Recording, resume, training, and rollout](software/lerobot-hei-rebot-lift/examples/hei_rebot_lift/README.md)
- [Robot configuration, lift units, and watchdog](software/lerobot-hei-rebot-lift/src/lerobot/robots/hei_rebot_lift/README.md)
- [VR deployment, controller tutorial, and self-checks](software/lerobot-hei-rebot-lift/examples/hei_rebot_lift/VR_mujoco_ik/README.md)

## 🙏 References & Acknowledgments

The development of HEI ReBot Lift benefits from several excellent open-source projects and community efforts. In particular, we would like to thank:

- **LeRobot**: for providing a unified robot interface, the LeRobotDataset format, training utilities, and policy implementations such as ACT and SmolVLA, which form a strong foundation for real-robot data collection, training, and deployment.
- **reBot / reBot-DevArm**: for open robotic arm hardware, model resources, and practical references for embodied AI open-source projects. It also inspired the way this project organizes hardware materials, deployment documentation, and reproducible workflows.

This project customizes and extends ideas from these open-source ecosystems, aiming to further lower the barrier to learning, reproducing, collecting data with, and deploying policies on a dual-arm lifting mobile robot.

## 📄 License

This project is built on top of Hugging Face LeRobot and keeps the LeRobot dataset, training, policy, and robot-interface ecosystem. Please also follow the original LeRobot license requirements.

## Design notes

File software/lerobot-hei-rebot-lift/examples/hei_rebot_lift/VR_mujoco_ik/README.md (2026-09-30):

# HEI ReBot Lift VR + MuJoCo IK

[English](README.md) | [中文](README_zh.md)

This directory contains the complete VR teleoperation pipeline:

- `telegrip/`: starts the HTTPS/WebXR page, receives VR headset/controller data, and publishes it through ZMQ at `tcp://*:5567`.
- `mujoco_ik/`: receives Telegrip VR data, visualizes the complete robot model (or the legacy dual-arm model) in MuJoCo, solves FK/IK with Pinocchio + CasADi, and publishes LeRobot-compatible actions to `tcp://*:6558`.
- `examples/hei_rebot_lift/vr_control.py`: receives those actions and publishes lightweight real-robot joint/lift feedback on `tcp://*:6559` for safe startup synchronization.
- `mujoco_ik/hei_robot_vr_mujoco_sim.py`: controls the complete robot model in pure simulation. It never publishes commands to the real robot.
- `mujoco_ik/hei_robot_keyboard_mujoco_sim.py`: controls the complete model by keyboard without VR or real-robot commands.
- `examples/hei_rebot_lift/record.py`: subscribes to `tcp://localhost:6558` and saves robot actions/observations into a LeRobotDataset.

## Layout

```text
VR_mujoco_ik/
  environment.yml          # Unified conda environment for Telegrip + MuJoCo IK
  run_telegrip.sh          # Start the VR Web page and VR data publisher
  run_mujoco_ik.sh         # Existing dual-arm real-robot action pipeline
  run_hei_robot_keyboard_sim.sh # Complete robot, keyboard-controlled pure simulation
  run_hei_robot_vr_sim.sh  # Complete robot, VR-controlled pure simulation
  run_hei_robot_vr_real.sh # Complete model + real-robot command bridge
  telegrip/                # WebXR/HTTPS/WebSocket/ZMQ VR bridge
  mujoco_ik/               # MuJoCo model, IK main program, Pinocchio tools
```

## Environment Setup

Each block beginning with `cd examples/...` starts in a new terminal at
`software/lerobot-hei-rebot-lift/`. Commands without `cd` assume you are already
in `VR_mujoco_ik/`. The wrappers activate `hei-rebot-vr` automatically; direct
Python commands need explicit activation. The LeRobot client uses a separate
`lerobot5` environment.

Use one shared conda environment instead of separate `VR_Telegrip` and `mujoco_vr` environments.

```bash
cd examples/hei_rebot_lift/VR_mujoco_ik
conda env create -f environment.yml
```

Update an existing environment:

```bash
conda env update -n hei-rebot-vr -f environment.yml --prune
```

Verify Pinocchio + CasADi:

```bash
conda activate hei-rebot-vr
env -u LD_LIBRARY_PATH python -c "import pinocchio as pin; from pinocchio import casadi as cpin; print(pin.__version__); print('casadi binding ok')"
```

## Startup Flow

### 1. Practice With Keyboard Simulation

Keyboard mode does not require Telegrip and never publishes real-robot commands:

```bash
cd examples/hei_rebot_lift/VR_mujoco_ik
./run_hei_robot_keyboard_sim.sh
```

Mode keys prevent conflicts between chassis, lift, and arm controls. Hold a
motion key for continuous movement and release it to stop. TCP translation and
rotation use the fixed robot frame: `+X` forward, `+Y` left, and `+Z` up.

| Mode/key | Function |
| --- | --- |
| `1` | Chassis mode |
| Chassis `W/S`, `A/D`, `Q/E` | Forward/back, strafe left/right, rotate left/right |
| `2` | Lift mode |
| Lift `I/K` | Raise/lower |
| `3` / `4` | Select left/right arm TCP control |
| `5` / `6` | Reset the left/right arm gradually; press once, or move that arm to cancel |
| Arm `W/S`, `A/D`, `R/F` | Translate TCP along positive/negative `X/Y/Z` |
| Arm `U/J`, `I/K`, `O/L` | Rotate TCP about positive/negative `Rx/Ry/Rz` |
| Arm `Z/X` | Open/close the selected gripper with stable scene grasping |
| `Shift` | Fine control at 25% of normal speed by default |
| `Space` | Clear chassis velocity immediately and hold both arms |
| `V` / `Backspace` / `Esc` | Toggle frames/reset the robot/quit |

Default speeds are `0.12 m/s` TCP translation, `35 deg/s` TCP rotation, and
`0.20 m/s` lift motion. Override them when needed:

```bash
./run_hei_robot_keyboard_sim.sh \
  --arm-linear-speed-m-s 0.08 \
  --arm-angular-speed-deg-s 25 \
  --lift-speed-m-s 0.12 \
  --fine-scale 0.2
```

Validate keyboard mappings, model loading, FK/IK, chassis, and stable grasping
without opening a window:

```bash
./run_hei_robot_keyboard_sim.sh --headless-check
```

### 2. Start Telegrip

```bash
cd examples/hei_rebot_lift/VR_mujoco_ik
./run_telegrip.sh
```

Open in the VR headset browser:

```text
https://COMPUTER_IP:8443
```

For example, use `https://192.168.31.245:8443` when that is your computer IP.
The robot IP is different (examples use `192.168.31.127`). Verify the address is
your computer before accepting the self-signed certificate warning.

### 3A. Test VR With the Complete Robot Model

<p align="center">
  HEI ReBot Lift VR simulation in MuJoCo
</p>

Start Telegrip first, then open another terminal:

```bash
cd examples/hei_rebot_lift/VR_mujoco_ik
./run_hei_robot_vr_sim.sh
```

This is the recommended first test for the new complete URDF. VR controls the
O-layout omnidirectional chassis, all four wheel animations, both arms, both
parallel grippers, and the lift. No command is published to port `6558` or sent
to the real robot.
The default debug scene provides a light-gray checker floor, gradient sky,
soft overhead/front-side lighting, an orange `4 x 4 m` safety boundary, a cyan
start area, and world axes at the start origin (X red, Y green, Z blue). A work
table, three colored cubes, and a locally stored textured YCB banana are also
included for pick-and-place practice.

The scene uses a stable grasp mode suitable for kinematic VR testing. Closing a
gripper near an object attaches the nearest object to that TCP while preserving
its relative pose. The object remains attached after releasing the grip button.
Opening the gripper releases it and places it on the table when it is above the
table footprint, or on the floor otherwise. Each arm can hold one object.

#### VR Controller Tutorial

<table align="center">
  <tr>
    <td align="center"><a href="../../../../../media/META-QUEST-BUTTON.jpg">Meta Quest system button on the right controller</a><br><b>Meta Quest System Button</b></td>
    <td align="center"><a href="../../../../../media/META-GRIP-BUTTON.jpg">Side grip button location</a><br><b>Grip: Side Button</b></td>
    <td align="center"><a href="../../../../../media/META-FRONT-TRIGGER.jpg">Front trigger location</a><br><b>Trigger: Front Trigger</b></td>
  </tr>
</table>

Click an image to view it at full size.

> [!IMPORTANT]
> **Calibrate the VR origin before control: hold the right controller's META QUEST BUTTON for about 3 seconds to recenter using the headset's current position and heading as the VR reference origin for this session.**
> **Recalibrate after changing your standing/seated position or operating direction. If controller motion and arm motion point in different directions or directional tracking feels wrong, stop control and recalibrate before continuing.**
> Sequence: **release both `grip` buttons → center the sticks → face the intended forward direction from your new position → hold the Meta Quest button for about 3 seconds → let tracking settle and hold `grip` again**. Verify direction with a small movement first.

The Meta Quest button recenters the **headset/VR reference frame**; `grip`
captures each arm's relative control origin. These are different operations.
Neither writes motor zeros nor replaces lift homing. Follow the calibration
procedure for both simulated and real VR control.

Arm motion uses relative poses. Each time a side's `grip` is pressed, the
current controller pose and corresponding robot TCP pose become the control
origin. Subsequent XYZ translation and rotation map to that TCP at a 1:1 scale.
Releasing `grip` holds the last arm target; pressing it again captures a new
origin, so the controller never needs to return to a fixed absolute pose.

| Controller input | Active when | Function |
| --- | --- | --- |
| Left `grip` | Held | Enable relative left-arm control and left-stick lift control |
| Right `grip` | Held | Enable relative right-arm control and chassis controls |
| Left/right `trigger` | Corresponding `grip` held | Press to open that gripper; release to close it |
| Left stick vertical | Left `grip` held | Push forward to raise the lift; pull back to lower it |
| Right stick vertical | Right `grip` held | Drive the chassis forward or backward |
| Right stick horizontal | Right `grip` held | Strafe the O-layout omnidirectional chassis left or right |
| Right `B` | Right `grip` held | Rotate the chassis clockwise |
| Left `Y` | Right `grip` held | Rotate the chassis counterclockwise |
| Right `A` | Right `grip` released | Return the right arm gradually to its default pose |
| Left `X` | Left `grip` released | Return the left arm gradually to its default pose |

Arm and gripper procedure:

1. Put the controller in a comfortable pose and clear the corresponding arm's workspace.
2. Hold that side's `grip` to capture the current control origin, then translate or rotate the controller to move the TCP.
3. Pure simulation starts with closed grippers; real startup first restores measured gripper state. While continuing to hold `grip`, press `trigger` to open the gripper and place it around the object.
4. Release `trigger` to close and grasp. Releasing `grip` stops arm tracking but preserves the last gripper state.
5. To release the object, hold the corresponding `grip` again and press `trigger`.

Chassis and lift procedure:

1. Right `grip` enables the chassis. Hold it while using the right stick for translation and right `B` or left `Y` for rotation. Releasing right `grip` immediately clears the motion request; physical braking still depends on host acceleration limits and hardware.
2. Left `grip` enables the lift. Hold it while moving the left stick forward/backward to raise/lower the platform. Releasing left `grip` stops the lift request; the real client holds the latest reported height.
3. Keep the corresponding stick centered when moving an arm without intending to move the chassis or lift.

First real-robot use and recovery:

1. After starting the real bridge, release both `grip` buttons and wait for `command bridge ARMED` in the terminal.
2. Test one arm at a time with small, slow controller motions and keep the emergency stop reachable.
3. A VR or robot-feedback timeout stops chassis/lift motion and locks the bridge. After recovery, release both `grip` buttons again to synchronize and re-arm.
4. In pure simulation, `F` toggles body frames and `R` resets the robot and scene objects. Full keyboard reset is disabled in real mode; use right `A` and left `X` to return the arms gradually.

Run the model and IK self-check without opening a viewer:

```bash
./run_hei_robot_vr_sim.sh --headless-check
```

Disable all environment elements and render only the robot with:

```bash
./run_hei_robot_vr_sim.sh --plain-scene
```

The banana asset is stored under
`mujoco_ik/model/HEI_robot_urdf/scene_assets/ycb_011_banana/`. See its
`SOURCE.md` for YCB attribution and CC BY 4.0 licensing details.

After practicing VR simulation, continue with the
[MuJoCo dataset, ACT training, and rollout workflow](mujoco_ik/SIM_DATASET_WORKFLOW.md).
It uses the same 18-D state/action schema and three camera names as the physical
robot without connecting to hardware.
MuJoCo runs independently in `hei-rebot-vr`, while recording, training, and
policy inference run in `lerobot5`.

### 3B. Control the Real Robot With the Complete Model

Before enabling commands, clear the robot workspace and make the emergency stop
reachable. Start the robot host and `teleoperate.py` as described in the HEI
ReBot Lift guide. `teleoperate.py` now publishes the current arm, gripper, and
lift state at 10 Hz on port `6559`. Then run:

```bash
cd examples/hei_rebot_lift/VR_mujoco_ik
./run_hei_robot_vr_real.sh --enable-real-publish
```

Real-robot mode loads only the complete robot URDF for IK and state
visualization. It does not load the simulation floor, table, graspable objects,
or other debug-scene elements. Its lift visualization defaults to about
`0.0286 m/s`, matching the current `18 rad/s` motor limit and `10 mm/rev` lead
screw's **theoretical full-stick speed cap**, not continuous measured motion.
Override the viewer with `--lift-speed-m-s VALUE` after changing the physical
lift parameters; this flag does not change motor speed. Standalone simulation
keeps its original `0.20 m/s` default.

The real bridge publishes `height_axis`, not the simulated lift height. The
LeRobot client combines that axis with reported robot height to produce
`action["height.pos"]` in millimeters; the host then regulates motor velocity.
After arming, the viewer integrates joystick input rather than continuously
correcting to measured lift height. Partial-stick response, acceleration,
latency, and load can therefore differ from the physical lift. The model is a
control visualization, not a continuously synchronized digital twin. See the
[driver guide](../../../src/lerobot/robots/hei_rebot_lift/README.md) for units and
the lead-screw conversion.

Real publishing remains locked until it receives fresh robot feedback and a
fresh Telegrip frame with both grip buttons released. The MuJoCo model is first
synchronized to the measured arm, gripper, and lift positions; only then does
the program publish the 14-joint/chassis/lift bridge protocol on `6558`. It maps
each URDF parallel-gripper opening to the physical Damiao gripper range (`-4.5`
open, `0` closed).

If either the VR stream or robot feedback times out, the bridge sends a zero
chassis/lift packet and returns to the locked state. After the connection
recovers, release both grip buttons to synchronize and arm again. The console
shows `feedback=<age>` and `bridge=locked/armed` for diagnosis.

For compatibility only, `--allow-no-feedback` bypasses startup synchronization
and robot-feedback freshness checks.
This mode can move the arms toward the simulated startup pose as soon as the
bridge is armed and is not recommended for hardware operation.

For a first hardware test, suspend the wheels, keep the lift away from both end
stops, and test one arm at a time at low motion amplitude. Confirm that the log
shows fresh feedback and `command bridge ARMED` before pressing grip. Closing
the viewer or losing either safety stream stops chassis/lift commands; the arms
hold their latest joint targets.

### 3C. Start the Existing Dual-Arm Real-Robot Pipeline

Use this **instead of**, not alongside, the complete-model real bridge.
Only one process may publish actions on `6558`, and only one of
`teleoperate.py` / `record.py` may publish feedback on `6559`. Stop
`teleoperate.py` before recording; after feedback reconnects, release both grips
to re-arm. For replay or policy rollout, stop VR command publishing and all
other computer-side robot controllers first.

```bash
cd examples/hei_rebot_lift/VR_mujoco_ik
./run_mujoco_ik.sh
```

## Network and Ports

```text
8443  Telegrip HTTPS VR page
8442  Telegrip WebSocket
5567  Telegrip publishes VR data, MuJoCo IK subscribes
6558  MuJoCo real bridge publishes actions, teleoperate.py/record.py subscribes
6559  teleoperate.py/record.py publishes real robot state for startup synchronization
6555  LeRobot client sends robot commands to the host
6556  Host observations and images; optionally displayed in Telegrip
```

Key settings in `telegrip/config.yaml`:

```yaml
vr:
  zmq_publish_endpoint: tcp://*:5567
  zmq_topic: vr_data
```

VR camera streaming is currently **disabled** (`vr_images.enabled: false`).
This does not stop host camera capture or dataset recording, and it does not
disable VR controller data. To enable robot camera display explicitly, edit:

```yaml
vr_images:
  enabled: true
  endpoint: tcp://ROBOT_IP:6556
```

`--remote-ip` on the LeRobot scripts does not update this YAML endpoint. Set both
when the robot IP changes. Port `6556` carries host observations and images;
it is not the Telegrip VR pose publisher on `5567`.

The real bridge defaults to a `1.0 s` VR timeout and a `1.0 s` feedback timeout;
the robot host separately uses a `1000 ms` command watchdog. These check different
links and do not replace the emergency stop. IK workspace projection and joint
limits are not collision avoidance or overload protection.

Default image keys:

```text
front
left_wrist
right_wrist
```

## Troubleshooting

### MuJoCo/Pinocchio Import Failure

```bash
conda activate hei-rebot-vr
env -u LD_LIBRARY_PATH python -c "import pinocchio as pin; from pinocchio import casadi as cpin; print(pin.__version__)"
```

All MuJoCo launch wrappers clear `LD_LIBRARY_PATH` and activate `hei-rebot-vr`.
Use `run_hei_robot_vr_sim.sh` / `run_hei_robot_vr_real.sh` for the complete model;
`run_mujoco_ik.sh` is the legacy dual-arm entry, not the default complete-model controller.

### VR Page Cannot Open

Make sure the computer and VR headset are on the same LAN and use:

```text
https://COMPUTER_IP:8443
```

Do not use `http`.

### Port Already in Use

```bash
ss -ltnp | rg ':(8443|8442|5567|6555|6556|6558|6559)\b'
```

Stop old Telegrip/MuJoCo IK processes and restart.

### Real Publishing Is Locked

`Real command publishing is locked` means the explicit safety flag is missing.
After checking the workspace and emergency stop, use
`./run_hei_robot_vr_real.sh --enable-real-publish`. If the viewer starts but shows
`bridge=locked`, check Telegrip data, the host, and one running client
(`teleoperate.py` or `record.py`), then release both grips together. Do not bypass
feedback checks to solve a connection problem.

### Self-Checks and Parameter Locations

Run these from `VR_mujoco_ik/`; they do not publish real commands:

```bash
./run_hei_robot_vr_sim.sh --headless-check
./run_hei_robot_vr_real.sh --headless-check
conda run --no-capture-output -n hei-rebot-vr python -m unittest discover -s mujoco_ik/tests -p 'test_*.py' -v
```

| Setting | Location | Scope |
| --- | --- | --- |
| Motor gains, velocity limits, lift lead and acceleration, cameras | `src/lerobot/robots/hei_rebot_lift/config_hei_rebot_lift.py` (software root) | Robot host; restart host after changes |
| Shared complete-model IK guard and workspace projection | `mujoco_ik/hei_robot_vr_mujoco_sim.py` | Complete-model simulation and real bridge |
| Real feedback/VR timeout and lift viewer speed | `mujoco_ik/hei_robot_vr_mujoco_real.py` / its CLI options | Computer-side real bridge |
| VR camera endpoint and image streaming | `telegrip/config.yaml` | Telegrip; separate from host camera capture settings |

`IK_TARGET_MAX_POSITION_ERROR_M` currently allows `0.100 m` position error.
This is a solution-acceptance tolerance, not a TCP accuracy guarantee. Raising
it can permit a larger gap between requested and executed targets.

### LeRobot Recording Has No Actions

Check that Telegrip is in VR, MuJoCo IK receives controller data, MuJoCo IK publishes to `tcp://*:6558`, and `record.py` shows increasing `saved_frames`.

## Chinese Version

- [README_zh.md](README_zh.md)

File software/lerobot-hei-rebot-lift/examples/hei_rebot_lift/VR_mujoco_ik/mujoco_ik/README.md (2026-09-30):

# MuJoCo IK

[English](README.md) | [中文](README_zh.md)

This is the MuJoCo + Pinocchio IK submodule in the HEI ReBot Lift VR teleoperation pipeline.

For environment installation, controller inputs, network configuration, and
safe real-robot startup, see the [VR guide](../README.md).
For simulated demonstrations, ACT training, and simulation rollout, see the
[MuJoCo dataset workflow](SIM_DATASET_WORKFLOW.md).
The workflow keeps the `hei-rebot-vr` simulator separate from the `lerobot5`
recording and inference clients.

## Choose an Entry Point

Run these wrappers from the parent `VR_mujoco_ik/` directory. Simulation
wrappers use `hei-rebot-vr`; recording and inference wrappers use `lerobot5`.
Run only one real-robot action publisher on `6558`.

| Entry | Model | Purpose |
| --- | --- | --- |
| `./run_hei_robot_keyboard_sim.sh` | `model/HEI_robot_urdf/` | Complete keyboard-only simulation; no VR or real commands |
| `./run_hei_robot_keyboard_dataset_sim.sh` | `model/HEI_robot_urdf/` | Keyboard demonstration simulation server (`hei-rebot-vr`) |
| `./run_hei_robot_keyboard_record.sh` | - | Keyboard demonstration recorder (`lerobot5`) |
| `./run_hei_robot_vr_sim.sh` | `model/HEI_robot_urdf/` | Complete robot, scene, VR, stable-grasp demonstration; no real commands |
| `./run_hei_robot_vr_dataset_sim.sh` | `model/HEI_robot_urdf/` | VR dataset simulation server (`hei-rebot-vr`) |
| `./run_hei_robot_mujoco_record.sh` | - | Independent LeRobotDataset recorder (`lerobot5`) |
| `./run_hei_robot_policy_sim.sh` | `model/HEI_robot_urdf/` | Policy simulation server (`hei-rebot-vr`) |
| `./run_hei_robot_mujoco_rollout.sh` | - | Independent policy inference client (`lerobot5`) |
| `./run_hei_robot_vr_real.sh --enable-real-publish` | `model/HEI_robot_urdf/` | Robot-only viewer and real command bridge; requires robot feedback and grip-release arming |
| `./run_mujoco_ik.sh` | `model/reBot_description/` | Legacy dual-arm realtime controller; not the complete robot entry |

In keyboard simulation, press `5` to reset the left arm gradually or `6` to
reset the right arm. Press once; moving that arm again or pressing `Space`
cancels the reset and holds its current pose. See the [parent guide](../README.md)
for the complete key map.

From the `software/lerobot-hei-rebot-lift` root, visualize a keyboard-simulation dataset with:

```bash
PYTHONPATH=src conda run --no-capture-output -n lerobot5 \
  lerobot-dataset-viz \
  --repo-id HGM/hei_rebot_lift_keyboard_mujoco \
  --root datasets/hei_rebot_lift_keyboard_mujoco \
  --episode-index 0
```

Real mode also needs the robot host and exactly one of `teleoperate.py` or
`record.py`. See the parent guide before enabling hardware commands.

## Offline Self-Checks

These checks do not publish real commands or require a VR headset:

```bash
./run_hei_robot_keyboard_sim.sh --headless-check
./run_hei_robot_vr_sim.sh --headless-check
./run_hei_robot_vr_real.sh --headless-check
conda run --no-capture-output -n hei-rebot-vr python -m unittest discover -s mujoco_ik/tests -p 'test_*.py' -v
```

Passing model/protocol checks does not validate physical motor zeros, directions,
limit switches, or load capacity; test those independently before real use.

Note: install `pinocchio`, `casadi`, `eigenpy`, and `coal-python` from the conda-forge versions defined in the parent `environment.yml`. Do not install `pin` separately with pip in this folder.

## Chinese Version

- [README_zh.md](README_zh.md)

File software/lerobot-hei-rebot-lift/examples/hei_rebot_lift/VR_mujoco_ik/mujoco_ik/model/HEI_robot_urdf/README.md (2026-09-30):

# HEI Robot URDF MuJoCo Validation

This directory contains the complete SW2URDF model and an independent MuJoCo
kinematic viewer. It does not modify or start the existing VR control program.

[English](README.md) | [中文](README_zh.md)

The following inspection commands start in this **model directory**, not the
software root. The wrapper automatically activates `hei-rebot-vr`.

## Model check

Compile the URDF and print every MuJoCo joint, axis, range, and qpos address:

```bash
./run_mujoco_sim.sh --headless-check
```

## Visualization

```bash
./run_mujoco_sim.sh
```

Viewer keyboard controls:

- `N` / `P`: select the next or previous controllable joint.
- `-` / `=`: decrease or increase the selected joint position.
- `O` / `C`: open or close both grippers.
- `R`: restore the neutral inspection pose.

## VR-controlled complete simulation

From the `VR_mujoco_ik` directory, start Telegrip and the new pure-simulation
entry point in separate terminals:

Terminal A:

```bash
./run_telegrip.sh
```

Terminal B (also in `VR_mujoco_ik/`):

```bash
./run_hei_robot_vr_sim.sh
```

The VR simulator uses both TCP frames for reduced Pinocchio/CasADi IK and
updates this complete MuJoCo model directly. It controls the two arms, parallel
grippers, lift, chassis translation/rotation, and all four wheel animations. It does not publish real
robot commands. See [`../../../README.md`](../../../README.md) for controls.

After validating pure simulation, the separate real-robot bridge can be started
from `VR_mujoco_ik` with:

```bash
./run_hei_robot_vr_real.sh --enable-real-publish
```

Do not use the real bridge until the robot workspace, emergency stop, startup
arm pose, wheel support, and both lift limit switches have been checked. Start
one robot host and one client first. The bridge requires fresh feedback and VR
with both grips released; wait for `command bridge ARMED`. Full startup and Meta
Quest recentering instructions are in the parent VR guide. Never run simulation
and real publishing together during beginner practice.

The left finger is the primary joint on each gripper. MuJoCo does not apply the
URDF `mimic` relationship, so the viewer explicitly updates the right finger to
the opposite displacement.

The model also contains fixed kinematic frames at the center of each gripper:

- `a_right_end_link` and `b_left_end_link`: center of the finger rails.
- `a_right_tcp` and `b_left_tcp`: nominal grasp point centered between the fingertips.

## Camera frames

The model contains three camera mount links and their standard optical frames:

- `front_camera_link` is fixed to `lift_carriage_link`.
- `left_wrist_camera_link` is fixed to `b_left_link6`.
- `right_wrist_camera_link` is fixed to `a_right_link6`.
- Their optical frames are `front_camera_optical_frame`,
  `left_wrist_camera_optical_frame`, and `right_wrist_camera_optical_frame`.

The SW2URDF camera links use local `+Z` forward, `+X` toward image left, and
`+Y` toward image up. Each optical frame converts this to the conventional
`+X` image right, `+Y` image down, and `+Z` forward convention.
`hei_robot_mujoco_scene.py` attaches the named MuJoCo cameras `front`,
`left_wrist`, and `right_wrist` to these frames.

All three cameras currently render at `640x480`. The front D435 uses an
approximate `42.5°` vertical field of view, while both wrist cameras temporarily
use `60°` until measured intrinsics are available. Render one image per camera:

```bash
cd software/lerobot-hei-rebot-lift/examples/hei_rebot_lift/VR_mujoco_ik
MUJOCO_GL=egl conda run --no-capture-output -n hei-rebot-vr \
  python mujoco_ik/preview_mujoco_cameras.py
```

Images are written to `mujoco_ik/outputs/camera_preview/`. Once camera
intrinsics are measured, update the vertical field of view with
`fovy = 2 * atan(height / (2 * fy))`.

## Export compiled MJCF

```bash
./run_mujoco_sim.sh \
  --headless-check \
  --save-mjcf /tmp/HEI_robot_urdf_compiled.xml
```

The exported file is useful for inspecting MuJoCo's interpretation of the URDF.
Keep the URDF as the source model; the compiled XML is a generated diagnostic
artifact and may need mesh-path adjustment if moved to another directory.

## Important conventions

- Arm joint limits follow the existing `reBot_dual_with_gripper.urdf` control conventions.
- Joint 2 uses the new SW link frame's local axis `0 -1 0`, physically matching the old model's rotated `0 0 -1` axis.
- `base_footprint` follows the standard `+X` forward, `+Y` left, `+Z` up convention.
- `base_footprint` is centered between the four wheel contact points at ground height.
- Lift and gripper prismatic joint positions are measured in meters. The lift range is `-0.8` to `0` m, matching the real `-800` to `0` mm convention.
- The viewer performs kinematic inspection only and does not call `mj_step`.
- Wheel motor IDs are 1 right front, 2 right rear, 3 left rear, 4 left front.
- Simulation grippers start closed. Hold grip and press trigger to open; release trigger to close. Releasing grip retains the last state. Real startup instead synchronizes measured gripper state.
- The stable-grasp scene attaches objects kinematically; joint limits and workspace projection are not collision avoidance.

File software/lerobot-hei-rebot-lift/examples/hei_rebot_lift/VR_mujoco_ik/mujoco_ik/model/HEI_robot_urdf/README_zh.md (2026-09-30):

# HEI 完整机器人 URDF 与 MuJoCo 验证

[English](README.md) | [中文](README_zh.md)

本目录保存 SW2URDF 导出的完整模型和独立运动学检查窗口，不会启动真机控制。
以下检查命令均从**本模型目录**执行，不是软件根目录；
脚本自动激活 `hei-rebot-vr`。

## 1. 模型检查

编译 URDF 并打印 MuJoCo 关节、轴、范围及 qpos 地址：

```bash
./run_mujoco_sim.sh --headless-check
```

## 2. 可视化

```bash
./run_mujoco_sim.sh
```

窗口按键：`N/P` 选择前后关节，`-/=` 减少/增加位置，`O/C` 张开/闭合两侧
夹爪，`R` 恢复检查姿态。只是运动学显示，不调用 `mj_step`。

## 3. 完整模型 VR 仿真与真机入口

切换到上三级 `VR_mujoco_ik/`，先完成该目录的
[VR 教程](../../../README_zh.md)。纯仿真分开两个终端运行：

```bash
./run_telegrip.sh
```

```bash
./run_hei_robot_vr_sim.sh
```

仿真控制双臂、平行夹爪、升降、底盘前后/横移/旋转及四轮动画，不发布真机命令。
先练习 Meta Quest 长按约 3 秒校准、grip 相对控制和释放停止。
稳定抓取模式是 TCP 绑定物体的运动学演示，不是接触力学验证。

完成硬件检查后，停止纯仿真，在机器人端启动 host，在电脑端先启动一个
`teleoperate.py` 或 `record.py` 客户端，再从 `VR_mujoco_ik/` 运行：

```bash
./run_hei_robot_vr_real.sh --enable-real-publish
```

需要新鲜 VR/实机反馈、同时松开两侧 grip，等待 `command bridge ARMED`。
启动 host 会上行回零，先检查上下限位与急停，不要同时开两种真机控制源。
真机入口只显示机器人；完整步骤见上级教程。

## 4. 平行夹爪与 TCP

每侧左手指是主控制关节。MuJoCo 不自动处理 URDF `mimic`，窗口程序显式更新
右手指为相反位移。固定坐标系：

- `a_right_end_link` / `b_left_end_link`：手指导轨中心。
- `a_right_tcp` / `b_left_tcp`：两指尖之间的名义抓取点。

仿真夹爪默认闭合，保持 grip 时按 trigger 张开、松 trigger 闭合，松 grip 保持
最后状态；真机启动先同步反馈的实际夹爪状态。

## 5. 相机 TF

模型包含三个随机器人运动的相机安装 link，以及对应的标准 optical frame：

- `front_camera_link` 挂载到 `lift_carriage_link`。
- `left_wrist_camera_link` 挂载到 `b_left_link6`。
- `right_wrist_camera_link` 挂载到 `a_right_link6`。
- 对应 optical frame 分别为 `front_camera_optical_frame`、
  `left_wrist_camera_optical_frame` 和 `right_wrist_camera_optical_frame`。

本次 SW2URDF 导出的 camera link 使用 `+Z` 朝镜头、`+X` 向画面左、`+Y`
向画面上；optical frame 将其转换为 `+X` 画面右、`+Y` 画面下、`+Z`
镜头前方。`hei_robot_mujoco_scene.py` 会在这些 frame 上创建三个 MuJoCo
具名相机：`front`、`left_wrist` 和 `right_wrist`。

当前三路分辨率均为 `640x480`。`front` 暂按 D435 RGB 的典型垂直视场角
`42.5°` 配置；两路腕部相机在取得实测内参前暂用 `60°`。一次性输出三路
预览图：

```bash
cd software/lerobot-hei-rebot-lift/examples/hei_rebot_lift/VR_mujoco_ik
MUJOCO_GL=egl conda run --no-capture-output -n hei-rebot-vr \
  python mujoco_ik/preview_mujoco_cameras.py
```

图片保存在 `mujoco_ik/outputs/camera_preview/`。相机内参确定后，应使用
`fovy = 2 * atan(height / (2 * fy))` 更新场景构建器中的垂直视场角。

## 6. 导出编译后的 MJCF

回到本模型目录执行：

```bash
./run_mujoco_sim.sh --headless-check --save-mjcf /tmp/HEI_robot_urdf_compiled.xml
```

导出的 XML 用于检查 MuJoCo 的解释结果，URDF 仍是源模型；移动 XML 后可能需要
调整 mesh 路径。

## 7. 模型约定

- 臂关节范围沿用旧 `reBot_dual_with_gripper.urdf` 控制约定。
- 关节 2 使用新 SW 局部轴 `0 -1 0`，物理方向对应旧模型旋转后的 `0 0 -1`。
- `base_footprint` 位于四轮接地点中心地面高度，`+X` 前、`+Y` 左、`+Z` 上。
- 升降与夹爪移动关节单位是米；升降 `-0.8..0 m` 对应实机 `-800..0 mm`。
- 轮电机 ID：1 右前、2 右后、3 左后、4 左前。
- 关节限位和工作空间投影不等于碰撞检测。

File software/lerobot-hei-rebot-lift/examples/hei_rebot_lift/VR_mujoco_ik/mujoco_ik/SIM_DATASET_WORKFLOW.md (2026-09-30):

# MuJoCo Dataset, Training, and Rollout

[English](SIM_DATASET_WORKFLOW.md) | [中文](SIM_DATASET_WORKFLOW_zh.md)

This workflow uses two independent processes and Conda environments. MuJoCo owns simulation, IK, camera rendering, and action execution. LeRobot owns dataset writing, training, and policy inference. ZMQ carries synchronized observations and actions between them; no physical robot is connected.

## 1. Architecture

| Process | Conda environment | Entry point | Responsibility |
| --- | --- | --- | --- |
| VR demonstration simulation | `hei-rebot-vr` | `run_hei_robot_vr_dataset_sim.sh` | Receive VR input, run MuJoCo, publish observations and demonstration actions |
| Keyboard demonstration simulation | `hei-rebot-vr` | `run_hei_robot_keyboard_dataset_sim.sh` | Receive keyboard input, run MuJoCo, and publish demonstration samples |
| VR dataset recorder | `lerobot5` | `run_hei_robot_mujoco_record.sh` | Receive VR simulation samples and write a LeRobotDataset |
| Keyboard dataset recorder | `lerobot5` | `run_hei_robot_keyboard_record.sh` | Receive keyboard simulation samples and write a LeRobotDataset |
| Policy simulation | `hei-rebot-vr` | `run_hei_robot_policy_sim.sh` | Run MuJoCo and execute policy actions |
| Policy inference | `lerobot5` | `run_hei_robot_mujoco_rollout.sh` | Load a policy, infer actions, and send them to simulation |

The default observation and command ports are TCP `6565` and `6566`. Use `--sim-ip 127.0.0.1` when both processes run on the same computer.

Keep the environments separate: do not install the LeRobot training stack into `hei-rebot-vr`.

## 2. Record VR Simulation Data

Start Telegrip and open its control page in the headset. Hold the **Meta Quest Button for three seconds** whenever the headset position/orientation changes or controller directions no longer match the robot.

Terminal 1, start the VR simulation:

```bash
cd software/lerobot-hei-rebot-lift/examples/hei_rebot_lift/VR_mujoco_ik
./run_hei_robot_vr_dataset_sim.sh --publish-fps 30
```

Terminal 2, start the LeRobot recorder:

```bash
cd software/lerobot-hei-rebot-lift/examples/hei_rebot_lift/VR_mujoco_ik
./run_hei_robot_mujoco_record.sh \
  --repo-id HGM/hei_rebot_lift_mujoco \
  --root datasets/hei_rebot_lift_mujoco \
  --num-episodes 10 \
  --episode-time-sec 30 \
  --fps 30 \
  --task "Pick up the red cube with the right gripper and place it in the center of the table."
```

Recorder keys:

| Key | Action |
| --- | --- |
| Right arrow | Finish and save the current episode early |
| Left arrow | Discard and re-record the current episode |
| `Esc` | Stop and finalize the dataset |

Use matching FPS values on both sides. The simulation control loop remains unrestricted and only publishes synchronized samples at `--publish-fps`; the recorder never starts MuJoCo.

To append data, use the same explicit `--root` and add `--resume`. If the processes run on different computers, pass the simulation computer address through `--sim-ip` and allow TCP ports `6565/6566`.

## 3. Record Keyboard Simulation Data

Keyboard recording does not require Telegrip. The existing `run_hei_robot_keyboard_sim.sh` is for control practice only and does not publish dataset samples. Use `run_hei_robot_keyboard_dataset_sim.sh` when recording.

Terminal 1:

```bash
cd software/lerobot-hei-rebot-lift/examples/hei_rebot_lift/VR_mujoco_ik
./run_hei_robot_keyboard_dataset_sim.sh --publish-fps 30
```

Terminal 2:

```bash
cd software/lerobot-hei-rebot-lift/examples/hei_rebot_lift/VR_mujoco_ik
./run_hei_robot_keyboard_record.sh \
  --repo-id HGM/hei_rebot_lift_keyboard_mujoco \
  --root datasets/hei_rebot_lift_keyboard_mujoco \
  --num-episodes 10 \
  --episode-time-sec 30 \
  --fps 30 \
  --task "Pick up the red cube with the right gripper and place it in the center of the table."
```

Use `1` for chassis, `2` for lift, `3/4` for left/right arm, and `5/6` to reset the arms. Chassis uses `W/S A/D Q/E`; lift uses `I/K`; arm translation uses `W/S A/D R/F`; arm rotation uses `U/J I/K O/L`; `Z/X` opens/closes the active gripper. Hold `Shift` for fine control, `Space` to stop/hold, and `Backspace` to reset the complete scene.

The recorder still uses Right Arrow to save early, Left Arrow to discard/re-record, and `Esc` to stop. Both processes listen for `Esc`, so the keyboard simulation also exits as a safety behavior.

## 4. Inspect Data

Enter the software repository root first:

```bash
cd software/lerobot-hei-rebot-lift
```

Visualize a complete keyboard-simulation episode in Rerun:

```bash
PYTHONPATH=src conda run --no-capture-output -n lerobot5 \
  lerobot-dataset-viz \
  --repo-id HGM/hei_rebot_lift_keyboard_mujoco \
  --root datasets/hei_rebot_lift_keyboard_mujoco \
  --episode-index 0
```

Episode index `0` is the first episode. `--root` must point to the local dataset directory containing `meta/info.json`; otherwise LeRobot attempts to download the repository from Hugging Face.

Inspect one frame and export all three camera images:

```bash
PYTHONPATH=src conda run --no-capture-output -n lerobot5 \
  python -u examples/hei_rebot_lift/VR_mujoco_ik/mujoco_ik/inspect_mujoco_dataset.py \
  --repo-id HGM/hei_rebot_lift_mujoco \
  --root datasets/hei_rebot_lift_mujoco \
  --episode-index 0 --frame-index 0
```

The command exports all three camera frames under `outputs/mujoco_dataset_sample/`. Before a full recording session, verify the 18-D state/action vectors, camera names, gripper units, lift range, and normalized yaw command.

## 5. Train ACT

Training runs only in `lerobot5`:

```bash
cd software/lerobot-hei-rebot-lift
PYTHONPATH=src conda run --no-capture-output -n lerobot5 lerobot-train \
  --dataset.repo_id=HGM/hei_rebot_lift_mujoco \
  --dataset.root=datasets/hei_rebot_lift_mujoco \
  --policy.type=act --policy.device=cuda --policy.push_to_hub=false \
  --output_dir=outputs/train/act_hei_rebot_lift_mujoco \
  --job_name=act_hei_rebot_lift_mujoco \
  --batch_size=8 --steps=100000 --save_freq=10000 --log_freq=200 \
  --num_workers=4 --wandb.enable=false
```

Use `--steps=1000` for an initial pipeline check.

## 6. Run a Policy in MuJoCo

Stop the VR demonstration simulation first. Terminal 1:

```bash
cd software/lerobot-hei-rebot-lift/examples/hei_rebot_lift/VR_mujoco_ik
./run_hei_robot_policy_sim.sh --publish-fps 30
```

Terminal 2:

```bash
./run_hei_robot_mujoco_rollout.sh \
  --model-id outputs/train/act_hei_rebot_lift_mujoco \
  --task "Pick up the red cube with the right gripper and place it in the center of the table." \
  --duration-sec 30 --fps 30 --device cuda
```

Inference only computes actions. The policy simulation process owns the MuJoCo window and execution. If inference stops or times out, the server holds arm/lift positions and zeros chassis velocity.

## 7. Compatibility Boundary

Simulation and hardware use the same 18-D field names, units, order, and three camera names. The stable grasp is still deterministic and does not reproduce real contact, friction, load, or imaging. Validate the task in simulation, then fine-tune with real demonstrations for sim-to-real use.

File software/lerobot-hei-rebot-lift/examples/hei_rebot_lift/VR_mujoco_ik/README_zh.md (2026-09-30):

# HEI ReBot Lift VR + MuJoCo IK

[English](README.md) | [中文](README_zh.md)

这个目录是一套完整的 VR 遥操作链路：

- `telegrip/`：启动 HTTPS/WebXR 页面，接收 VR 头显和手柄数据，并通过 ZMQ 发布到 `tcp://*:5567`。
- `mujoco_ik/`：接收 Telegrip 的 VR 数据，用 MuJoCo 显示完整机器人模型（或旧双臂模型），用 Pinocchio + CasADi 做正逆解，并通过 ZMQ 发布 LeRobot 可用的动作命令到 `tcp://*:6558`。
- `examples/hei_rebot_lift/vr_control.py`：接收动作，同时在 `tcp://*:6559` 发布轻量实机关节/升降反馈，用于真机启动前安全同步。
- `mujoco_ik/hei_robot_vr_mujoco_sim.py`：使用完整机器人模型进行纯仿真 VR 控制，不会向真实机器人发送命令。
- `mujoco_ik/hei_robot_keyboard_mujoco_sim.py`：使用键盘控制完整机器人仿真，不需要 VR，也不会连接实机。
- LeRobot 录制端 `examples/hei_rebot_lift/record.py` 订阅 `tcp://localhost:6558`，把动作和机器人观测保存成数据集。

## 目录结构

```text
VR_mujoco_ik/
  environment.yml          # 统一 conda 环境，Telegrip + MuJoCo IK 共用
  run_telegrip.sh          # 启动 VR Web 页面和 VR 数据发布
  run_mujoco_ik.sh         # 原双臂实机动作链路
  run_hei_robot_keyboard_sim.sh # 完整机器人键盘纯仿真
  run_hei_robot_vr_sim.sh  # 完整机器人 VR 纯仿真
  run_hei_robot_vr_real.sh # 完整模型 + 真实机器人命令桥接
  telegrip/                # WebXR/HTTPS/WebSocket/ZMQ VR 桥
  mujoco_ik/               # MuJoCo 模型、IK 主程序、Pinocchio 工具
```

## 一体化环境部署

以下以 `cd examples/...` 开头的命令块，均在新终端的
`software/lerobot-hei-rebot-lift/` 目录执行。不带 `cd` 的命令默认已进入
`VR_mujoco_ik/`。启动脚本自动激活 `hei-rebot-vr`；直接运行 Python 检查命令时
需要手动激活。LeRobot 客户端仍使用独立的 `lerobot5` 环境。

建议只保留一个 conda 环境，不再分 `VR_Telegrip` 和 `mujoco_vr` 两套。

```bash
cd examples/hei_rebot_lift/VR_mujoco_ik
conda env create -f environment.yml
```

如果环境已经存在，更新即可：

```bash
conda env update -n hei-rebot-vr -f environment.yml --prune
```

验证：

```bash
conda activate hei-rebot-vr
env -u LD_LIBRARY_PATH python -c "import pinocchio as pin; from pinocchio import casadi as cpin; print(pin.__version__); print('casadi binding ok')"
```

看到 `casadi binding ok` 就说明正逆解库链路正常。

## 启动流程

键盘纯仿真只需一个终端；VR 纯仿真通常两个终端；真机还需机器人 host 和一个电脑客户端，共四个终端。

### 1. 先用键盘熟悉完整机器人仿真

键盘模式不需要启动 Telegrip，也不会向真实机器人发布命令：

```bash
cd examples/hei_rebot_lift/VR_mujoco_ik
./run_hei_robot_keyboard_sim.sh
```

程序通过模式键避免底盘、升降和双臂键位冲突。按住运动键连续运动，松开后停止；
TCP 的位置和姿态增量均以机器人固定坐标系定义：`+X` 前、`+Y` 左、`+Z` 上。

| 模式/按键 | 功能 |
| --- | --- |
| `1` | 底盘模式 |
| 底盘模式 `W/S`、`A/D`、`Q/E` | 前后、左右横移、左右旋转 |
| `2` | 升降模式 |
| 升降模式 `I/K` | 上升/下降 |
| `3` / `4` | 选择左臂/右臂末端控制 |
| `5` / `6` | 左臂/右臂缓慢复位；按一下即可，重新操作对应臂会取消复位 |
| 手臂模式 `W/S`、`A/D`、`R/F` | TCP `X/Y/Z` 正负方向平移 |
| 手臂模式 `U/J`、`I/K`、`O/L` | TCP `Rx/Ry/Rz` 正负方向旋转 |
| 手臂模式 `Z/X` | 当前夹爪张开/闭合，并支持场景物体稳定抓取 |
| `Shift` | 按住进入精细低速控制，默认速度为正常速度的 25% |
| `Space` | 立即清除底盘速度并保持双臂当前位置 |
| `V` / `Backspace` / `Esc` | 显示坐标系/整机复位/退出 |

默认 TCP 平移速度为 `0.12 m/s`、姿态速度为 `35 deg/s`、升降速度为
`0.20 m/s`。可通过参数调整，例如：

```bash
./run_hei_robot_keyboard_sim.sh \
  --arm-linear-speed-m-s 0.08 \
  --arm-angular-speed-deg-s 25 \
  --lift-speed-m-s 0.12 \
  --fine-scale 0.2
```

无窗口检查键盘映射、模型、双臂 FK/IK、底盘和稳定抓取：

```bash
./run_hei_robot_keyboard_sim.sh --headless-check
```

### 2. 启动 Telegrip

电脑端：

```bash
cd examples/hei_rebot_lift/VR_mujoco_ik
./run_telegrip.sh
```

VR 头显浏览器访问：

```text
https://电脑IP:8443
```

例如自己的电脑 IP 为 `192.168.31.245`，则访问 `https://192.168.31.245:8443`。
机器人 IP 是另一个地址（示例为 `192.168.31.127`），不要混用。首次遇到自签名
证书提示时，先确认地址确实是自己的电脑，再继续访问。

### 3A. 用完整模型测试 VR 仿真

需要把 VR 操作保存为 ACT 训练数据时，请阅读
[VR MuJoCo 仿真数据采集流程](SIM_DATA_COLLECTION_README_zh.md)。采集器直接运行在纯仿真
循环内；不要使用实机 `record.py` 录制这类数据。

<p align="center">
  HEI ReBot Lift MuJoCo VR 仿真场景
</p>

先启动 Telegrip，然后在另一个终端执行：

```bash
cd examples/hei_rebot_lift/VR_mujoco_ik
./run_hei_robot_vr_sim.sh
```

这是完整 URDF 的推荐首次测试入口。VR 可控制 O 型全向底盘、四个轮子的旋转动画、
左右机械臂、两个平行夹爪和升降平台。程序不发布 `6558` 端口的动作，也不会连接实机。
默认调试场景包含浅灰方格地面、渐变天空、柔和的顶部/前侧灯光、橙色 `4 x 4 m`
安全区域、青色启动区域，以及位于启动原点的世界坐标轴（X 红、Y 绿、Z 蓝）。
场景还加入了操作桌、三个彩色方块和一个保存于项目本地的 YCB 纹理香蕉，可用于
抓取和放置练习。

场景采用适合运动学 VR 调试的“稳定抓取模式”：夹爪在物体附近由张开变为闭合时，
程序会把最近的物体绑定到对应 TCP，并保留抓取瞬间的相对位置和朝向。松开 grip
不会掉落物体；再次张开夹爪才会释放。物体位于桌面范围上方时会稳定放到桌面，
否则放到地面。每条机械臂同时最多抓取一个物体。

#### VR 手柄使用教程

<table align="center">
  <tr>
    <td align="center"><a href="../../../../../media/META-QUEST-BUTTON.jpg">右手柄 Meta Quest 系统按钮位置</a><br><b>Meta Quest 系统按钮</b></td>
    <td align="center"><a href="../../../../../media/META-GRIP-BUTTON.jpg">侧面 grip 握把按钮位置</a><br><b>Grip：侧面握把</b></td>
    <td align="center"><a href="../../../../../media/META-FRONT-TRIGGER.jpg">前方 trigger 扳机位置</a><br><b>Trigger：前扳机</b></td>
  </tr>
</table>

点击图片可查看大图。

> [!IMPORTANT]
> **控制前先校准 VR 原点：长按右手柄的 META QUEST BUTTON 约 3 秒，以当前头显位置和朝向重新居中，作为本次操作的 VR 参考原点。**
> **换了站立/坐姿位置或操作朝向，都需要重新长按约 3 秒校准。发现手柄与机械臂运动方向不一致、方向不跟手时，也要先停止控制并重新校准，不要继续强行操作。**
> 校准顺序：**松开左右两侧 `grip` → 摇杆回中 → 在新的操作位置面向期望的前方 → 长按 Meta Quest 按钮约 3 秒 → 稳定后重新按住 `grip`**，先小幅移动确认方向。

Meta Quest 按钮校准的是**头显/VR 参考坐标**；`grip` 建立的是每条臂的相对控制
原点，两者不是一回事。这也不是给机械臂电机写零位，更不会代替升降回零；
仿真和真机 VR 操作都要遵守上述校准步骤。

程序使用相对位姿控制。每次按下某侧 `grip` 时，程序会把当时的手柄位姿和对应
机械臂 TCP 位姿记为控制原点；之后手柄的 XYZ 位移与旋转以 1:1 比例映射到 TCP。
松开 `grip` 后机械臂保持最后目标，再次按下时会重新建立原点，因此不会要求手柄
回到固定的绝对位置。

| 手柄输入 | 生效条件 | 功能 |
| --- | --- | --- |
| 左侧 `grip` | 按住 | 启用左臂相对位姿控制，同时允许左摇杆控制升降 |
| 右侧 `grip` | 按住 | 启用右臂相对位姿控制，同时允许右摇杆和旋转按键控制底盘 |
| 左/右 `trigger` | 对应侧 `grip` 按住 | 按下张开对应夹爪，松开闭合夹爪 |
| 左摇杆上下 | 左侧 `grip` 按住 | 向前推使升降上升，向后拉使升降下降 |
| 右摇杆上下 | 右侧 `grip` 按住 | 控制底盘前进和后退 |
| 右摇杆左右 | 右侧 `grip` 按住 | 控制 O 型全向底盘向左和向右横移 |
| 右手 `B` | 右侧 `grip` 按住 | 底盘顺时针旋转 |
| 左手 `Y` | 右侧 `grip` 按住 | 底盘逆时针旋转 |
| 右手 `A` | 右侧 `grip` 松开 | 右臂缓慢回到默认姿态 |
| 左手 `X` | 左侧 `grip` 松开 | 左臂缓慢回到默认姿态 |

机械臂与夹爪操作步骤：

1. 把手柄放在舒适位置，确认目标机械臂周围没有障碍物。
2. 按住对应侧 `grip`，以当前位姿建立控制原点，然后平移或旋转手柄控制末端。
3. 纯仿真夹爪默认闭合，真机启动先同步反馈的实际夹爪状态。保持 `grip` 时按下 `trigger` 张开夹爪，将夹爪移动到物体两侧。
4. 松开 `trigger` 使夹爪闭合并抓取。松开 `grip` 只会停止机械臂跟随，夹爪仍保持最后状态。
5. 需要释放物体时，再次按住对应侧 `grip` 并按下 `trigger`。

底盘与升降操作步骤：

1. 右侧 `grip` 是底盘使能键。保持右侧 `grip`，使用右摇杆控制前后与横移；使用
   右手 `B` 或左手 `Y` 控制旋转。松开右侧 `grip` 立即清除运动请求；实机减速
   仍受 host 加减速限制和硬件响应影响，不代表瞬间机械停止。
2. 左侧 `grip` 是升降使能键。保持左侧 `grip`，前后推动左摇杆控制上升和下降；
   松开左侧 `grip` 后停止升降请求；真机客户端以最新反馈高度作为保持目标。
3. 控制机械臂但不希望底盘或升降运动时，保持相应摇杆处于中心位置。

真机首次使用与恢复：

1. 启动真机桥后先松开左右两个 `grip`，等待终端显示 `command bridge ARMED`。
2. 首次测试每次只操作一条机械臂，采用小幅、缓慢的手柄动作，并确保急停可随时按下。
3. VR 数据或实机反馈超时后，底盘和升降会停止，桥接进入锁定状态；连接恢复后，
   再次松开左右两个 `grip` 完成同步和解锁。
4. MuJoCo 仿真窗口中，`F` 显示或隐藏 body 坐标系，`R` 同时复位机器人和场景物体。
   真机模式禁用键盘 `R` 全复位，请使用右手 `A` 和左手 `X` 分别缓慢复位机械臂。

不打开图形窗口，只检查模型编译和两臂 FK/IK：

```bash
./run_hei_robot_vr_sim.sh --headless-check
```

如需关闭全部环境元素，只显示机器人：

```bash
./run_hei_robot_vr_sim.sh --plain-scene
```

香蕉模型保存在
`mujoco_ik/model/HEI_robot_urdf/scene_assets/ycb_011_banana/`，其 YCB 来源、
引用方式和 CC BY 4.0 许可证说明见该目录的 `SOURCE.md`。

熟悉 VR 仿真后，可继续阅读
[MuJoCo 数据采集、ACT 训练与仿真推理](mujoco_ik/SIM_DATASET_WORKFLOW_zh.md)。
这套流程保留与真机相同的 18 维动作/状态字段和三相机名称，但不会连接真实机器人。
MuJoCo 使用 `hei-rebot-vr` 独立运行，采集、训练和推理使用 `lerobot5` 独立运行。

### 3B. 用完整模型控制真实机器人

解锁真机命令前，请清空机器人工作区并确保急停可随时按下。按 HEI ReBot Lift
文档先启动机器人 host 和 `teleoperate.py`。`teleoperate.py` 会在 `6559` 端口以
10 Hz 回传实机当前双臂、夹爪和升降位置，然后执行：

```bash
cd examples/hei_rebot_lift/VR_mujoco_ik
./run_hei_robot_vr_real.sh --enable-real-publish
```

真机模式只加载完整机器人 URDF，用于逆解计算和实机状态显示；不会加载仿真地面、
桌子、可抓取物体及其他调试场景元素。真机模式的升降显示速度默认为约
`0.0286 m/s`，对应当前 `18 rad/s` 电机限速和 `10 mm/rev` 丝杆导程；硬件参数
对应的是**满摇杆时的理论最高速**，不是全过程实测同步。硬件参数变化后可用
`--lift-speed-m-s VALUE` 覆盖显示速度；这个参数不会改变电机转速。
单独仿真仍保留原来的 `0.20 m/s` 默认值。

真机桥接发布的是 `height_axis`，不是仿真高度。LeRobot 客户端结合机器人反馈
高度生成毫米单位的 `action["height.pos"]`，host 再根据高度误差控制电机速度。
解锁后，viewer 主要按摇杆积分显示，不会持续用实测高度校正，因此半摇杆响应、
加减速、网络延迟和负载都会造成显示与实机不一致。它是控制可视化，不是全过程
同步的数字孪生。单位和丝杆换算详见
[机器人驱动说明](../../../src/lerobot/robots/hei_rebot_lift/README_zh.md)。

程序同时收到新鲜的实机反馈，以及一帧“两个 grip 都已松开”的新鲜 Telegrip
数据后，才会解锁真机发布。解锁前，MuJoCo 会先同步实测的双臂、夹爪和升降位置，
再通过 `6558` 发布 14 个双臂/夹爪关节、底盘和升降命令。平行夹爪的 URDF
米制开度会转换为达妙夹爪的 `-4.5` rad 张开和 `0` rad 闭合。

VR 数据或实机反馈任意一路超时，程序都会先发送底盘/升降停止包，再退回锁定状态。
连接恢复后，必须重新松开左右两个 grip，完成同步后才能再次解锁。终端日志中的
`feedback=<延迟>` 和 `bridge=locked/armed` 可用于判断当前阶段。

`--allow-no-feedback` 只用于兼容旧流程，它会跳过实机姿态同步和反馈新鲜度检查，解锁后机械臂可能
直接追向仿真启动姿态，因此不建议在真实硬件上使用。

首次实机测试建议架起底盘轮子，让升降远离上下限位，每次只测一条手臂且减小动作幅度。
按 grip 前先确认日志已显示新鲜反馈和 `command bridge ARMED`。关闭 viewer，或 VR/
实机反馈超时时，底盘和升降会停止，机械臂保持最后关节目标。

### 3C. 启动原有双臂实机 MuJoCo IK 链路

此入口与完整模型真机桥接**二选一**，不能同时发布到 `6558`。
`teleoperate.py` 与 `record.py` 也只能运行一个，因为它们都在 `6559` 发布反馈。
录制前停止遥操作；反馈恢复后松开两侧 grip 重新解锁。回放或策略推理前，应停止
VR 真机发布及其他电脑端机器人控制程序。

同一台电脑另一个终端：

```bash
cd examples/hei_rebot_lift/VR_mujoco_ik
./run_mujoco_ik.sh
```

## 网络和端口

```text
8443  Telegrip HTTPS VR 页面
8442  Telegrip WebSocket
5567  Telegrip 发布 VR 数据，MuJoCo IK 订阅
6558  MuJoCo 真机桥发布动作，teleoperate.py/record.py 订阅
6559  teleoperate.py/record.py 发布实机状态，供启动姿态同步
6555  LeRobot 客户端向 host 发送机器人控制命令
6556  host 观测和图像，Telegrip 可选订阅显示
```

`telegrip/config.yaml` 里主要看两个地方：

```yaml
vr:
  zmq_publish_endpoint: tcp://*:5567
  zmq_topic: vr_data
```

当前 VR 相机回传**默认关闭**（`vr_images.enabled: false`），但不影响 host
采集相机、数据录制或 VR 手柄数据。确实需要头显画面时，再显式开启：

```yaml
vr_images:
  enabled: true
  endpoint: tcp://机器人IP:6556
```

LeRobot 脚本的 `--remote-ip` 不会自动更新此 YAML 地址，机器人换 IP 时两处都要
检查。`6556` 是 host 的观测/图像通道，不是 Telegrip 的 `5567` VR 位姿通道。

真机桥接默认 VR 超时和反馈超时均为 `1.0 s`；host 另有 `1000 ms` 命令看门狗。
它们保护不同链路，不能代替急停。IK 工作空间投影与关节限位也不等于碰撞检测或
过载保护。

三路图像 key 默认是：

```text
front
left_wrist
right_wrist
```

## 常见问题

### MuJoCo/Pinocchio 导入失败

优先用下面命令验证：

```bash
conda activate hei-rebot-vr
env -u LD_LIBRARY_PATH python -c "import pinocchio as pin; from pinocchio import casadi as cpin; print(pin.__version__)"
```

若仅清除 `LD_LIBRARY_PATH` 后才能导入，说明动态库搜索路径有冲突。
各 MuJoCo 启动脚本都会清除它并激活 `hei-rebot-vr`；完整模型请选择
`run_hei_robot_vr_sim.sh` / `run_hei_robot_vr_real.sh`，`run_mujoco_ik.sh`
仅用于旧双臂入口。

### VR 页面打不开

检查电脑和 VR 头显是否在同一局域网，访问地址必须是：

```text
https://电脑IP:8443
```

不是 `http`。

### 端口被占用

常见是旧的 Telegrip 或 MuJoCo IK 没关。查端口：

```bash
ss -ltnp | rg ':(8443|8442|5567|6555|6556|6558|6559)\b'
```

关掉旧进程后重新启动。

### 真机发布锁定

`Real command publishing is locked` 表示缺少明确的安全确认参数。检查工作区与
急停后，用 `./run_hei_robot_vr_real.sh --enable-real-publish` 启动。
如果窗口已打开但显示 `bridge=locked`，检查 Telegrip、host，以及一个已运行的
客户端（`teleoperate.py` 或 `record.py`），再同时松开两侧 grip。不要通过跳过
反馈检查解决网络连接问题。

### 自检与参数位置

在 `VR_mujoco_ik/` 目录执行，以下检查不发布真机命令：

```bash
./run_hei_robot_vr_sim.sh --headless-check
./run_hei_robot_vr_real.sh --headless-check
conda run --no-capture-output -n hei-rebot-vr python -m unittest discover -s mujoco_ik/tests -p 'test_*.py' -v
```

| 参数 | 所在文件 | 生效范围 |
| --- | --- | --- |
| 电机增益/限速、丝杆导程/加速度、相机 | 软件根目录下 `src/lerobot/robots/hei_rebot_lift/config_hei_rebot_lift.py` | 机器人 host；修改后重启 host |
| 完整模型 IK 判断与工作空间投影 | `mujoco_ik/hei_robot_vr_mujoco_sim.py` | 完整模型仿真与真机桥接共用 |
| 实机反馈/VR 超时、升降显示速度 | `mujoco_ik/hei_robot_vr_mujoco_real.py` 及命令行选项 | 电脑端真机桥接 |
| VR 相机地址与图像显示 | `telegrip/config.yaml` | Telegrip；与机器人相机采集配置分开 |

`IK_TARGET_MAX_POSITION_ERROR_M` 当前为 `0.100 m`，是接受 IK 解的误差阈值，
不表示末端控制精度能达到该值；调大后，请求目标与实际执行目标可能相差更多。

### LeRobot 录制没有动作

检查链路顺序：

1. Telegrip 页面已经启动并进入 VR。
2. MuJoCo IK 窗口已经启动，并能收到 VR 控制器数据。
3. MuJoCo IK 正在向 `tcp://*:6558` 发布动作。
4. `record.py` 已启动并能看到 saved_frames 增长。

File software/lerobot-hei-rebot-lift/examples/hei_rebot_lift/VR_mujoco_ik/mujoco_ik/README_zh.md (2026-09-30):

# MuJoCo IK

[English](README.md) | [中文](README_zh.md)

这是 HEI ReBot Lift VR 遥操作链路里的 MuJoCo + Pinocchio IK 子模块。

统一部署、手柄操作、网络配置和真机安全启动请看 [VR 使用教程](../README_zh.md)。
仿真示教采集、ACT 训练和仿真推理请看
[MuJoCo 数据采集、训练与推理](SIM_DATASET_WORKFLOW_zh.md)。
该流程将 `hei-rebot-vr` 仿真进程与 `lerobot5` 采集/推理进程完全分开。

## 选择启动入口

以下脚本在上一级 `VR_mujoco_ik/` 目录执行。仿真脚本自动使用
`hei-rebot-vr`，采集和推理脚本自动使用 `lerobot5`。
`6558` 端口同一时间只能保留一个真机动作发布程序。

| 入口 | 模型 | 用途 |
| --- | --- | --- |
| `./run_hei_robot_keyboard_sim.sh` | `model/HEI_robot_urdf/` | 完整机器人键盘纯仿真；不需要 VR，不发布真机命令 |
| `./run_hei_robot_keyboard_dataset_sim.sh` | `model/HEI_robot_urdf/` | 键盘示教数据采集用仿真服务端（`hei-rebot-vr`） |
| `./run_hei_robot_keyboard_record.sh` | - | 键盘示教数据采集客户端（`lerobot5`） |
| `./run_hei_robot_vr_sim.sh` | `model/HEI_robot_urdf/` | 完整机器人、场景、VR、稳定抓取演示；不发布真机命令 |
| `./run_hei_robot_vr_dataset_sim.sh` | `model/HEI_robot_urdf/` | VR 数据采集用仿真服务端（`hei-rebot-vr`） |
| `./run_hei_robot_mujoco_record.sh` | - | 独立 LeRobotDataset 采集客户端（`lerobot5`） |
| `./run_hei_robot_policy_sim.sh` | `model/HEI_robot_urdf/` | 策略推理用仿真服务端（`hei-rebot-vr`） |
| `./run_hei_robot_mujoco_rollout.sh` | - | 独立策略推理客户端（`lerobot5`） |
| `./run_hei_robot_vr_real.sh --enable-real-publish` | `model/HEI_robot_urdf/` | 仅机器人显示与真机桥接；需要实机反馈及松开握把解锁 |
| `./run_mujoco_ik.sh` | `model/reBot_description/` | 旧双臂 realtime 控制程序，不是完整机器人入口 |

键盘仿真中按 `5` 可让左臂缓慢复位，按 `6` 可让右臂缓慢复位；按一下即可，
重新操作对应机械臂或按 `Space` 会取消复位并保持当前位置。完整键位见
[上级使用教程](../README_zh.md)。

在 `software/lerobot-hei-rebot-lift` 根目录可视化键盘仿真数据集：

```bash
PYTHONPATH=src conda run --no-capture-output -n lerobot5 \
  lerobot-dataset-viz \
  --repo-id HGM/hei_rebot_lift_keyboard_mujoco \
  --root datasets/hei_rebot_lift_keyboard_mujoco \
  --episode-index 0
```

真机模式还需要机器人 host，以及 `teleoperate.py` 或 `record.py` 中的一个。
启用真机命令前请先阅读上级教程。

## 无界面自检

以下命令不发布真机命令，也不需要 VR 头显：

```bash
./run_hei_robot_keyboard_sim.sh --headless-check
./run_hei_robot_vr_sim.sh --headless-check
./run_hei_robot_vr_real.sh --headless-check
conda run --no-capture-output -n hei-rebot-vr python -m unittest discover -s mujoco_ik/tests -p 'test_*.py' -v
```

模型与协议自检通过，不代表实机零位、方向、限位开关和负载能力已经验证；
这些仍需单独进行硬件调试。

注意：`pinocchio`、`casadi`、`eigenpy`、`coal-python` 请使用上级 `environment.yml` 里的 conda-forge 版本安装，不要在这里单独 `pip install pin`。

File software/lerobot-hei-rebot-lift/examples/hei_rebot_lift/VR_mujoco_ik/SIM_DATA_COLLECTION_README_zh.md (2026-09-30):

# VR MuJoCo 仿真数据采集流程

这份流程只用于“Quest/Telegrip → MuJoCo 仿真 → LeRobotDataset”训练数据，**不要运行实机
`record.py`**。采集器已经接在 `mujoco_ik/hei_robot_vr_mujoco_sim.py` 的同一个仿真循环中，
因此保存的观测和 VR 控制后的仿真状态是同步的。

## 1. 环境和目录

在 WSL2 Ubuntu 中执行。先确认环境：

```bash
conda activate hei-rebot-vr
cd /mnt/e/code_product/act_hei_robot/software/lerobot-hei-rebot-lift/examples/hei_rebot_lift/VR_mujoco_ik
python -c "import mujoco, zmq, pinocchio; print(mujoco.__version__)"
python -c "from lerobot.common.datasets.lerobot_dataset import LeRobotDataset; print('LeRobotDataset OK')"
```

如果第二条失败，需在当前环境安装与项目训练环境相同版本的 `lerobot`；不要把实机
相机/机器人 SDK 当成仿真采集依赖。

如果 `hei-rebot-vr` 因 Python 3.10 无法安装当前 LeRobot，程序仍可采集：它会自动把每条
轨迹保存为 `raw_episodes/episode_*.npz`。采集完成后，在 ACT/训练环境执行文末的转换命令。

## 2. 启动 VR 和仿真

终端 A：

```bash
cd /mnt/e/code_product/act_hei_robot/software/lerobot-hei-rebot-lift/examples/hei_rebot_lift/VR_mujoco_ik
sed -i 's/\r$//' run_telegrip.sh run_hei_robot_vr_sim.sh
conda activate hei-rebot-vr
./run_telegrip.sh
```

在 Quest 浏览器打开 Telegrip 页面，点击 `Start VR`，确认 Telegrip 终端出现
`VR client connected` 和控制器数据日志。

终端 B：

```bash
cd /mnt/e/code_product/act_hei_robot/software/lerobot-hei-rebot-lift/examples/hei_rebot_lift/VR_mujoco_ik
conda activate hei-rebot-vr
env -u LD_LIBRARY_PATH python -u mujoco_ik/hei_robot_vr_mujoco_sim.py \
  --record \
  --record-root /mnt/e/code_product/ACT/outputs/data/hei_vr_sim \
  --record-repo-id local/hei_vr_sim \
  --record-task "VR control HEI ReBot in MuJoCo" \
  --record-episodes 20 \
  --record-fps 20
```

`--record-root` 可以改成训练机器上的任意目录。默认每帧保存：双臂 12 个关节、双夹爪、
升降、底盘 x/y/yaw，共 17 维 `observation.state`，一张 MuJoCo `front` 相机图像，以及
下一帧状态作为 `action`。当前没有真实相机，也不会向真实机器人发布指令。
如果目录中已经有 raw episode，程序会自动从现有最大编号之后继续保存，不会覆盖旧文件；
`--record-episodes 37` 表示本次新录制 37 条。

## 3. 每条 episode 的操作

先在窗口里用 VR 做一次完整示范，准备好后点击 MuJoCo 窗口：

- `Space`：开始录制；再次按 `Space`：结束并保存当前 episode，保存后程序会自动复位仿真环境。
- `Backspace`：丢弃当前 episode，不写入数据集。
- `R`：手动复位机器人和场景，并丢弃未完成录制（保存后通常不需要再按）。
- `F`：显示/隐藏 MuJoCo 坐标系。
- `Esc`：关闭窗口并退出。

建议每个任务先录 3 条短轨迹确认动作方向和图像，再录目标数量。不要在 VR 断流、仿真窗口
没有更新或夹爪状态明显异常时保存；这种 episode 用 `Backspace` 丢弃。

## 4. 检查数据

```bash
conda activate hei-rebot-vr
python - <<'PY'
from pathlib import Path
import json
root = Path('/mnt/e/code_product/ACT/outputs/data/hei_vr_sim')
info = json.loads((root / 'meta' / 'info.json').read_text())
print('episodes =', info['total_episodes'])
print('fps =', info['fps'])
print('root =', root)
PY
```

至少确认 `total_episodes > 0`，并且每条轨迹都有 `observation.state`、
`observation.images.front`、`action` 和 `task`。采集完成后再复制到 ACT 训练环境，或直接
在已安装训练依赖的环境中运行训练命令。

如果目录里是 `raw_episodes` 而不是 `meta/info.json`，先转换：

```bash
cd /mnt/e/code_product/ACT
conda activate lerobot-mujoco
python -m act_exp.convert_vr_dataset \
  --input-root /mnt/e/code_product/ACT/outputs/data/hei_vr_sim \
  --output-root /mnt/e/code_product/ACT/outputs/data/hei_vr_sim \
  --repo-id local/hei_vr_sim
```

## 5. 与 ACT 训练的关系

该采集器输出的是标准 LeRobotDataset，不需要再运行实机 `record.py`。如果训练脚本要求
数据集名，将 `repo_id`/数据根目录改成脚本使用的名字；例如：

```bash
conda activate lerobot-mujoco
python -m act_exp.train \
  --task hei_vr_sim \
  --seed 0 \
  --steps 20000 \
  --output-dir /mnt/e/code_product/act_hei_robot/outputs/train/hei_vr_sim_seed0
```

如果现有训练脚本没有 `hei_vr_sim` 任务配置，需要先把任务名、数据根目录和 17 维状态配置
加入训练入口；不要把它伪装成 14 维 ALOHA 数据。视觉 ACT 训练使用 `front` 图像，纯状态
策略验证则只使用 `observation.state`。

## 6. 常见问题

- **窗口显示 VR waiting**：先确认 Telegrip 在终端 A 运行、Quest 已点击 `Start VR`，并且
  仿真使用 `tcp://localhost:5567`；如果 Telegrip 在另一台主机，改 `--vr-endpoint`。
- **`LeRobotDataset` 导入失败**：当前 `hei-rebot-vr` 只有 VR/IK 依赖，安装项目的 lerobot
  数据集依赖，或改用已安装 `lerobot` 的训练环境运行仿真程序。
- **数据目录已有旧数据**：程序会追加到已有数据集；要重新开始，请先备份后删除该任务的
  `meta/data` 目录，再重新运行。不要删除整个项目目录。
- **图像黑屏/全黑**：确认使用了本版本 `hei_robot_mujoco_scene.py`（已加入 `front` 相机和
  场景灯光），并按文档用 `env -u LD_LIBRARY_PATH` 启动。

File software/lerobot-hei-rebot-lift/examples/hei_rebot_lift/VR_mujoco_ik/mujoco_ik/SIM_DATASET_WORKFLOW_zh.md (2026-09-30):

# MuJoCo 数据采集、训练与推理

[English](SIM_DATASET_WORKFLOW.md) | [中文](SIM_DATASET_WORKFLOW_zh.md)

这套流程使用两个完全独立的进程和 Conda 环境。MuJoCo 只负责仿真、IK、三路相机渲染和动作执行；LeRobot 只负责数据集、训练与策略推理。两边通过 ZMQ 传输同步的观测和动作，不会连接真实机器人。

## 1. 架构

| 进程 | Conda 环境 | 入口 | 职责 |
| --- | --- | --- | --- |
| VR 示教仿真 | `hei-rebot-vr` | `run_hei_robot_vr_dataset_sim.sh` | 接收 VR，运行 MuJoCo，发布观测和示教动作 |
| 键盘示教仿真 | `hei-rebot-vr` | `run_hei_robot_keyboard_dataset_sim.sh` | 接收键盘输入，运行 MuJoCo，发布观测和示教动作 |
| VR 数据采集 | `lerobot5` | `run_hei_robot_mujoco_record.sh` | 接收 VR 仿真数据并写入 LeRobotDataset |
| 键盘数据采集 | `lerobot5` | `run_hei_robot_keyboard_record.sh` | 接收键盘仿真数据并写入 LeRobotDataset |
| 策略仿真 | `hei-rebot-vr` | `run_hei_robot_policy_sim.sh` | 运行 MuJoCo，接收策略动作 |
| 策略推理 | `lerobot5` | `run_hei_robot_mujoco_rollout.sh` | 加载模型、计算动作并发回仿真 |

默认使用：

- 观测端口：`6565`
- 命令端口：`6566`
- 同一台电脑运行时：`--sim-ip 127.0.0.1`

不要把 LeRobot 训练依赖安装进 `hei-rebot-vr`。两个环境分别按现有 VR 部署教程和 LeRobot 部署教程安装即可。

## 2. 录制 VR 仿真数据

先启动 Telegrip，并在头显中打开控制页面。换位置、换朝向或发现手柄方向不一致时，长按 **Meta Quest Button 3 秒**重新校准头显原点。

终端一启动 VR 示教仿真：

```bash
cd software/lerobot-hei-rebot-lift/examples/hei_rebot_lift/VR_mujoco_ik
./run_hei_robot_vr_dataset_sim.sh --publish-fps 30
```

终端二启动数据采集：

```bash
cd software/lerobot-hei-rebot-lift/examples/hei_rebot_lift/VR_mujoco_ik
./run_hei_robot_mujoco_record.sh \
  --repo-id HGM/hei_rebot_lift_mujoco \
  --root datasets/hei_rebot_lift_mujoco \
  --num-episodes 10 \
  --episode-time-sec 30 \
  --fps 30 \
  --task "Pick up the red cube with the right gripper and place it in the center of the table."
```

采集端快捷键：

| 按键 | 功能 |
| --- | --- |
| 右方向键 | 提前结束并保存当前 episode |
| 左方向键 | 丢弃当前 episode 并重新录制 |
| `Esc` | 停止录制并整理数据集 |

仿真端和采集端的 FPS 应保持一致。仿真端始终运行高频控制，只按 `--publish-fps` 发布同步样本；采集端不会启动 MuJoCo。

继续追加数据：

```bash
./run_hei_robot_mujoco_record.sh \
  --repo-id HGM/hei_rebot_lift_mujoco \
  --root datasets/hei_rebot_lift_mujoco \
  --resume --num-episodes 10 --fps 30
```

如果仿真和采集不在同一台电脑，在采集命令中把 `--sim-ip` 改成运行 MuJoCo 的电脑 IP，并放行 TCP `6565/6566`。

## 3. 录制键盘仿真数据

键盘采集不需要启动 Telegrip。原有的 `run_hei_robot_keyboard_sim.sh` 仅用于练习控制，不发布数据；采集时必须使用下面的 `run_hei_robot_keyboard_dataset_sim.sh`。

终端一启动键盘示教仿真：

```bash
cd software/lerobot-hei-rebot-lift/examples/hei_rebot_lift/VR_mujoco_ik
./run_hei_robot_keyboard_dataset_sim.sh --publish-fps 30
```

终端二启动键盘数据采集：

```bash
cd software/lerobot-hei-rebot-lift/examples/hei_rebot_lift/VR_mujoco_ik
./run_hei_robot_keyboard_record.sh \
  --repo-id HGM/hei_rebot_lift_keyboard_mujoco \
  --root datasets/hei_rebot_lift_keyboard_mujoco \
  --num-episodes 10 \
  --episode-time-sec 30 \
  --fps 30 \
  --task "Pick up the red cube with the right gripper and place it in the center of the table."
```

键盘控制：

| 按键 | 功能 |
| --- | --- |
| `1` | 底盘模式：`W/S` 前后、`A/D` 横移、`Q/E` 旋转 |
| `2` | 升降模式：`I/K` 上升/下降 |
| `3` / `4` | 左臂/右臂模式 |
| `W/S A/D R/F` | 机械臂 TCP 的 X/Y/Z 平移 |
| `U/J I/K O/L` | 机械臂 TCP 的 Rx/Ry/Rz 旋转 |
| `Z/X` | 当前机械臂夹爪打开/闭合 |
| `5/6` | 左臂/右臂复位 |
| `Shift` | 精细低速控制 |
| `Space` | 停止并保持 |
| `Backspace` | 整机和场景复位 |

采集程序仍使用右方向键提前保存、左方向键丢弃重录、`Esc` 停止。由于两个进程都监听键盘，按 `Esc` 时键盘仿真也会退出，这是正常的安全行为。

## 4. 检查数据

先进入软件仓库根目录：

```bash
cd software/lerobot-hei-rebot-lift
```

使用 Rerun 可视化键盘仿真数据集中的完整 episode：

```bash
PYTHONPATH=src conda run --no-capture-output -n lerobot5 \
  lerobot-dataset-viz \
  --repo-id HGM/hei_rebot_lift_keyboard_mujoco \
  --root datasets/hei_rebot_lift_keyboard_mujoco \
  --episode-index 0
```

`--episode-index 0` 表示第 1 集。`--root` 必须指向实际包含 `meta/info.json` 的本地数据集目录；找不到该文件时，LeRobot 会尝试从 Hugging Face 下载数据。

检查某一帧的字段并导出三路相机图像：

```bash
PYTHONPATH=src conda run --no-capture-output -n lerobot5 \
  python -u examples/hei_rebot_lift/VR_mujoco_ik/mujoco_ik/inspect_mujoco_dataset.py \
  --repo-id HGM/hei_rebot_lift_mujoco \
  --root datasets/hei_rebot_lift_mujoco \
  --episode-index 0 --frame-index 0
```

输出图像位于 `outputs/mujoco_dataset_sample/`。正式录制前先确认：

- `observation.state` 和 `action` 都是 18 维；
- 图像键为 `front`、`left_wrist`、`right_wrist`；
- 夹爪闭合为 `0 rad`，打开为 `-4.5 rad`；
- `height.pos` 范围为 `-800~0 mm`；
- `theta.vel` 为 `[-1, 1]` 归一化值。

## 5. 训练 ACT

训练只使用 `lerobot5`：

```bash
cd software/lerobot-hei-rebot-lift
PYTHONPATH=src conda run --no-capture-output -n lerobot5 lerobot-train \
  --dataset.repo_id=HGM/hei_rebot_lift_mujoco \
  --dataset.root=datasets/hei_rebot_lift_mujoco \
  --policy.type=act \
  --policy.device=cuda \
  --policy.push_to_hub=false \
  --output_dir=outputs/train/act_hei_rebot_lift_mujoco \
  --job_name=act_hei_rebot_lift_mujoco \
  --batch_size=8 \
  --steps=100000 \
  --save_freq=10000 \
  --log_freq=200 \
  --num_workers=4 \
  --wandb.enable=false
```

首次联调可将 `--steps` 改为 `1000`。

## 6. 在 MuJoCo 中推理

先关闭 VR 示教仿真。终端一启动策略仿真：

```bash
cd software/lerobot-hei-rebot-lift/examples/hei_rebot_lift/VR_mujoco_ik
./run_hei_robot_policy_sim.sh --publish-fps 30
```

终端二在 `lerobot5` 中启动推理：

```bash
./run_hei_robot_mujoco_rollout.sh \
  --model-id outputs/train/act_hei_rebot_lift_mujoco \
  --task "Pick up the red cube with the right gripper and place it in the center of the table." \
  --duration-sec 30 --fps 30 --device cuda
```

推理程序只负责模型计算；MuJoCo 窗口、机器人状态和动作执行都由策略仿真进程负责。推理超时或退出时，仿真服务端会保持机械臂和升降位置，并把底盘速度置零。

## 7. 数据兼容边界

仿真与真机使用相同的 18 维字段、单位、顺序和三相机名称，因此策略结构可以复用。但稳定抓取仍是确定性吸附逻辑，视觉、摩擦、负载与真实成像存在差异。建议先用仿真验证任务链路，再用真实示教数据微调。

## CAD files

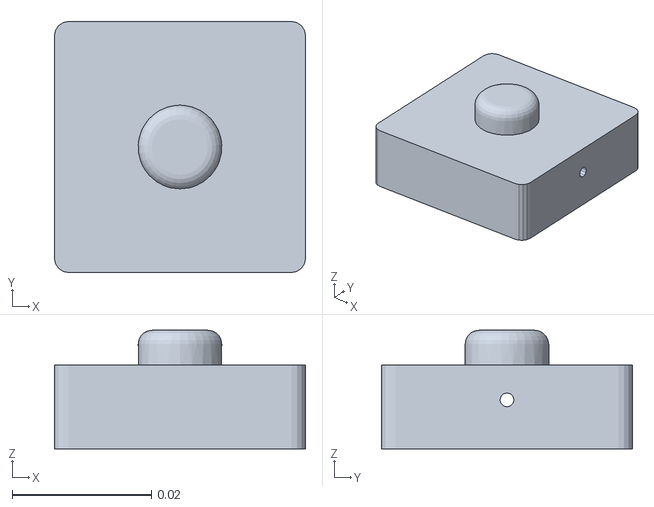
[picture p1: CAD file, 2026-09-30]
software/lerobot-hei-rebot-lift/examples/hei_rebot_lift/VR_mujoco_ik/mujoco_ik/model/HEI_robot_urdf/meshes/front_camera_link.STL
0.036 x 0.036 x 0.017

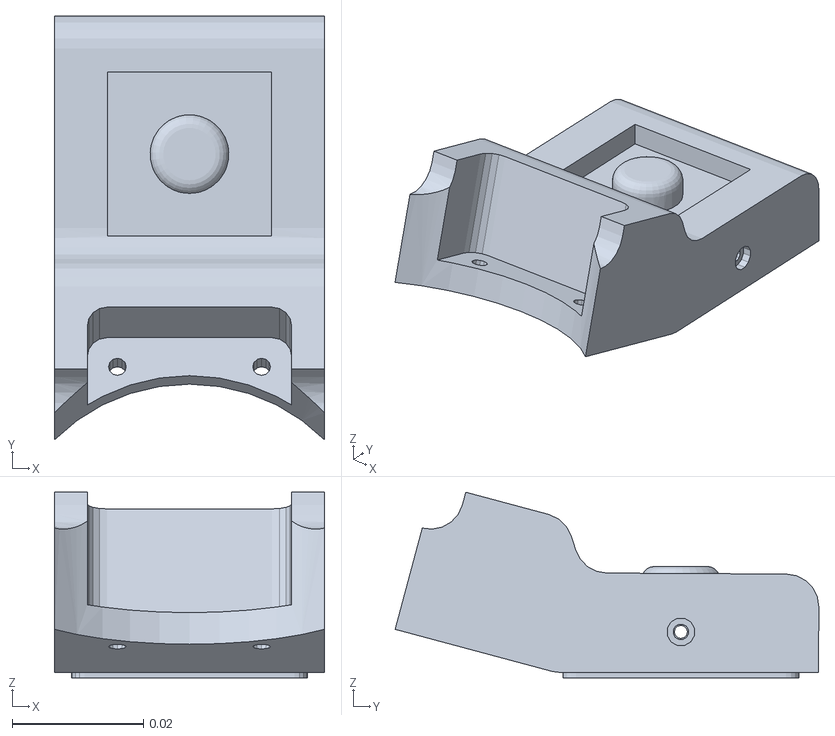
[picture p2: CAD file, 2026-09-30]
software/lerobot-hei-rebot-lift/examples/hei_rebot_lift/VR_mujoco_ik/mujoco_ik/model/HEI_robot_urdf/meshes/right_wrist_camera_link.STL
0.0412 x 0.0647 x 0.0283

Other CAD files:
software/lerobot-hei-rebot-lift/examples/hei_rebot_lift/VR_mujoco_ik/mujoco_ik/model/HEI_robot_urdf/meshes/left_wrist_camera_link.STL

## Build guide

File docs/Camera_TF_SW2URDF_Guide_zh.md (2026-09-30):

# HEI ReBot Lift 相机 TF 与 SW2URDF 建模指南

本文用于在 SolidWorks / SW2URDF 中为 HEI ReBot Lift 增加三台相机的坐标系：

- `front`：机器人前视相机，建议使用 Intel RealSense D435。
- `left_wrist`：左机械臂腕部相机。
- `right_wrist`：右机械臂腕部相机。

当前阶段只建立相机的机械安装关系和 TF。相机内参、图像采集以及 MuJoCo 渲染相机将在 URDF 导出并验证后接入程序。

## 1. 推荐的 TF 树

建议保留现有机械臂的 link 和 joint 名称，只新增以下相机节点：

```text
lift_carriage_link
└── front_camera_link
    └── front_camera_optical_frame

a_right_link6
└── right_wrist_camera_link
    └── right_wrist_camera_optical_frame

b_left_link6
└── left_wrist_camera_link
    └── left_wrist_camera_optical_frame
```

推荐父链接如下：

| 相机 | 父链接 | 原因 |
| --- | --- | --- |
| 前视相机 | `lift_carriage_link` | 相机随升降平台一起上下运动 |
| 右腕相机 | `a_right_link6` | 相机随右腕运动，但不随夹爪手指开合 |
| 左腕相机 | `b_left_link6` | 相机随左腕运动，但不随夹爪手指开合 |

如果前视相机实际固定在底盘而不是升降平台，应将它的父链接改成对应的底盘固定 link。不要仅根据外观看起来的位置选择父链接，应根据相机实际随哪个部件运动来确定。

## 2. 坐标系如何建立

### 2.1 相机机械坐标系

每台相机先建立一个 `camera_link`，原点放在 RGB 镜头的光心位置，而不是外壳中心或安装孔中心。

建议采用以下右手坐标系：

- `+X`：从镜头向外，指向相机正在观察的方向。
- `+Y`：相机左侧。
- `+Z`：相机上方。

从相机后方向镜头观察方向看，`+Y` 指向左，`+Z` 指向上。可用右手定则检查：`X × Y = Z`。

### 2.2 标准光学坐标系

视觉算法和 ROS 通常使用 optical frame：

- `+Z`：镜头朝向，即图像前方。
- `+X`：图像右侧。
- `+Y`：图像下方。

因此，每个 `camera_link` 下再建立一个同原点的 `camera_optical_frame`。从上述机械坐标系到 optical frame 的固定旋转为：

```xml
<origin xyz="0 0 0" rpy="-1.57079632679 0 -1.57079632679"/>
```

注意：MuJoCo 相机默认沿局部 `-Z` 方向观察。不要为了适配 MuJoCo 而改变 URDF 的标准相机坐标系；后续应在 MuJoCo 场景或转换代码中处理该差异。

### 2.3 当前 `HEI_robot_urdf_2` 的实际坐标约定

本次 SolidWorks 导出的三个 `camera_link` 使用另一套同样合法的右手坐标系：

- `+Z`：镜头前方。
- `+X`：画面左侧。
- `+Y`：画面上方。

因此，合入项目时采用以下旋转建立标准 optical frame：

```xml
<origin xyz="0 0 0" rpy="0 0 3.14159265358979"/>
```

不要把第 2.2 节适用于“`+X` 朝镜头”的旋转直接套到本次导出的模型上。后续若重新建立相机坐标系，应先确认镜头方向对应 camera link 的哪根轴，再选择转换关系。

## 3. SolidWorks 中的操作建议

1. 在机器人总装中加入简化的相机零件或装配体。
2. 按真实安装支架和方向完成配合，确保相机跟随正确的父部件。
3. 在 RGB 镜头光心创建坐标系。
4. 令坐标系 `+X` 穿过镜头朝外，`+Z` 指向画面上方，再按右手定则确定 `+Y`。
5. 在 SW2URDF 中将相机作为独立 child link，通过 `fixed` joint 连接到父链接。
6. 相机外壳网格可以相对 `camera_link` 偏移，但 `camera_link` 原点仍应位于镜头光心。
7. 如果 SW2URDF 不方便创建没有网格的 optical frame，可先导出机械相机 link，再手动向 URDF 添加 optical frame。

三个相机的安装 joint 都必须使用 `fixed`，不要使用 revolute、continuous 或 prismatic。

## 4. 名称规范

建议使用以下名称，不使用空格或中文：

| 部位 | Link | Joint | Optical frame | Optical joint |
| --- | --- | --- | --- | --- |
| 前视 | `front_camera_link` | `front_camera_joint` | `front_camera_optical_frame` | `front_camera_optical_joint` |
| 左腕 | `left_wrist_camera_link` | `left_wrist_camera_joint` | `left_wrist_camera_optical_frame` | `left_wrist_camera_optical_joint` |
| 右腕 | `right_wrist_camera_link` | `right_wrist_camera_joint` | `right_wrist_camera_optical_frame` | `right_wrist_camera_optical_joint` |

这些名称与项目中的数据键 `front`、`left_wrist`、`right_wrist` 一一对应，后续接入仿真采集时更容易核对。

## 5. URDF 模板

前视相机示例：

```xml
<link name="front_camera_link"/>

<joint name="front_camera_joint" type="fixed">
  <!-- X Y Z 和 R P Y 由 SolidWorks 实际装配位置决定 -->
  <origin xyz="X Y Z" rpy="R P Y"/>
  <parent link="lift_carriage_link"/>
  <child link="front_camera_link"/>
</joint>

<link name="front_camera_optical_frame"/>

<joint name="front_camera_optical_joint" type="fixed">
  <origin xyz="0 0 0" rpy="-1.57079632679 0 -1.57079632679"/>
  <parent link="front_camera_link"/>
  <child link="front_camera_optical_frame"/>
</joint>
```

左腕相机把父链接改为 `b_left_link6`，右腕相机把父链接改为 `a_right_link6`，并使用第 4 节规定的名称。

腕部相机不要挂在左右手指 link 上，否则夹爪开合时相机也会错误移动。

## 6. D435 的坐标系

第一阶段建议把 `front_camera_link` 的原点放在 D435 RGB 彩色相机的光心，以它作为 `front` 图像的 TF 来源。

后续如果使用 RGB-D 点云，可以继续增加：

```text
front_camera_link
├── front_color_frame
│   └── front_color_optical_frame
└── front_depth_frame
    └── front_depth_optical_frame
```

彩色与深度光心之间的平移和旋转应读取 D435 的出厂标定外参，不要根据外壳尺寸估算。如果深度图已经通过 RealSense SDK 对齐到彩色图，数据采集可以继续以彩色 optical frame 为参考。

## 7. 单位换算

SW2URDF 导出前后重点检查单位：

- SolidWorks 常用毫米，URDF 的 `xyz` 使用米：毫米数值除以 `1000`。
- SolidWorks 常用角度，URDF 的 `rpy` 使用弧度：角度乘以 `π / 180`。
- `rpy` 的顺序固定为 roll、pitch、yaw，不要交换顺序。

建议记录原始测量值和换算值，避免后续无法追溯：

| 相机 | xyz（mm） | rpy（deg） | xyz（m） | rpy（rad） |
| --- | --- | --- | --- | --- |
| front |  |  |  |  |
| left_wrist |  |  |  |  |
| right_wrist |  |  |  |  |

## 8. 建模信息记录表

完成模型时请填写以下内容。之后把导出的 URDF 和这张表交给程序侧，即可继续制作 MuJoCo 三相机渲染、仿真数据采集和训练链路。

```text
前视相机 front
  型号：D435 / 其他：
  父链接：lift_carriage_link / 其他：
  原点：RGB 光心 / 其他：
  相对父链接 xyz（mm）：
  相对父链接 rpy（deg）：
  镜头朝向对应父坐标系：+X / -X / +Y / -Y / +Z / -Z
  画面上方对应父坐标系：+X / -X / +Y / -Y / +Z / -Z
  采集内容：RGB / RGB-D

左腕相机 left_wrist
  型号：
  父链接：b_left_link6
  原点：RGB 光心
  相对父链接 xyz（mm）：
  相对父链接 rpy（deg）：
  镜头朝向对应父坐标系：
  画面上方对应父坐标系：

右腕相机 right_wrist
  型号：
  父链接：a_right_link6
  原点：RGB 光心
  相对父链接 xyz（mm）：
  相对父链接 rpy（deg）：
  镜头朝向对应父坐标系：
  画面上方对应父坐标系：
```

如果不方便准确填写 `rpy`，只需给出相机相对父链接的 `xyz`、镜头朝向和画面上方方向，程序侧也可以据此计算旋转。

## 9. 导出与检查清单

建议先导出为新文件，例如 `HEI_robot_urdf_with_cameras.urdf`，验证通过后再替换正式模型。

- 保留现有机械臂 link 和 joint 名称，避免破坏 IK 和控制程序。
- 三个安装 joint 均为 `fixed`。
- `front_camera_link` 会随升降平台移动。
- 左右腕相机分别跟随对应的 `link6`，不会随夹爪手指开合。
- 镜头朝向、画面上方和左右方向符合第 2 节约定。
- 所有 link 和 joint 名称唯一。
- 相机 TF link 通常不需要 collision；若添加外壳 collision，应使用简化几何体。
- 若相机 link 添加惯性参数，应使用合理质量和惯量，不能全部为零。
- 使用 `check_urdf` 检查树结构，再使用 MuJoCo 编译并分别预览三路相机画面。

URDF 中的 camera frame 负责描述安装位姿；MuJoCo 的具名 `<camera>`、分辨率、视场角和离屏渲染仍需要在仿真场景或加载程序中配置。完成新 URDF 后，再进行这部分接入。

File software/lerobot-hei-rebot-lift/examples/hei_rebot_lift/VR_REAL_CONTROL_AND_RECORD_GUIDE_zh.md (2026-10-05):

# HEI ReBot Lift：VR 真机控制、三相机预览与数据录制完整流程

本文适用于当前设备和目录：

- 机器人 Jetson IP：`10.163.141.128`
- Windows/WSL IP：`10.163.141.53`
- 电脑项目：`/mnt/e/code_product/act_hei_robot/software/lerobot-hei-rebot-lift`
- 机器人项目：`/home/jetson/hei-rebot-lift-main/software/lerobot-hei-rebot-lift`
- WSL Conda：`/mnt/e/DevSoft/miniconda3-wsl`
- WSL VR 环境：`hei-rebot-vr`
- WSL 客户端环境：`hei-rebot-client`
- Windows Rerun 环境：`E:\DevSoft\anaconda\envs\lerobot-mujoco`

## 1. 系统组成

```text
Quest 手柄
  -> Telegrip (8443/8442 -> 5567)
  -> MuJoCo IK 真机桥
  -> 动作端口 6558
  -> teleoperate.py 或 record.py
  -> 机器人 host (6555)

机器人电机状态和三路相机
  -> 机器人 host (6556)
  -> teleoperate.py 或 record.py
  -> 状态反馈 6559 -> MuJoCo IK 真机桥
  -> Windows Rerun 9876（仅显示）
```

`teleoperate.py` 和 `record.py` 二选一，严禁同时运行。它们都会控制机器人并绑定反馈端口 `6559`。

## 2. 启动前安全检查

1. 清空机器人工作范围，第一次测试不要拿物体。
2. 急停按钮放在操作者随手可按的位置。
3. 启动机器人 host、执行升降归零时，需要按设备要求释放急停。
4. VR 两侧 grip 先全部松开，摇杆回中。
5. 同一时间只允许一个 `6558` 动作发布器和一个机器人客户端。

## 3. 第一个终端：机器人 Jetson host

必须先进入仓库根目录。不要在 `examples/.../VR_mujoco_ik` 中设置 `PYTHONPATH=src`，因为那里没有 `src` 目录。

```bash
cd /home/jetson/hei-rebot-lift-main/software/lerobot-hei-rebot-lift
export PYTHONPATH="$PWD/src"
conda run --no-capture-output -n lerobot hei-rebot-lift-host
```

也可以写成一条命令：

```bash
cd /home/jetson/hei-rebot-lift-main/software/lerobot-hei-rebot-lift
PYTHONPATH="$PWD/src" conda run --no-capture-output -n lerobot hei-rebot-lift-host
```

截图中的错误：

```text
ModuleNotFoundError: No module named 'lerobot'
```

就是因为在错误目录使用了相对的 `PYTHONPATH=src`。正确执行上述两条命令即可，不需要重建机器人 Conda 环境。

host 正常后保持终端运行。它负责电机、升降归零、三路相机以及端口 `6555/6556`。

电脑 Windows PowerShell 可检查：

```powershell
Test-NetConnection 10.163.141.128 -Port 6555
Test-NetConnection 10.163.141.128 -Port 6556
```

两项的 `TcpTestSucceeded` 都应为 `True`。

## 4. Windows：启动原生 Rerun Viewer

WSL 内的 Mesa 驱动不支持 Rerun 需要的 `R32Float`，因此 Viewer 在 Windows 原生运行，机器人客户端仍留在 WSL。

在 Windows PowerShell 执行：

```powershell
E:\DevSoft\anaconda\envs\lerobot-mujoco\Scripts\rerun.exe `
  --bind 0.0.0.0 `
  --port 9876 `
  --memory-limit 4GB
```

保持 Rerun 窗口打开。检查监听端口：

```powershell
Get-NetTCPConnection -LocalPort 9876 -State Listen
```

## 5. 第二个 WSL 终端：启动 Telegrip

```bash
source /mnt/e/DevSoft/miniconda3-wsl/etc/profile.d/conda.sh
conda activate hei-rebot-vr

cd /mnt/e/code_product/act_hei_robot/software/lerobot-hei-rebot-lift/examples/hei_rebot_lift/VR_mujoco_ik
sed -i 's/\r$//' run_telegrip.sh run_hei_robot_vr_real.sh
chmod +x run_telegrip.sh run_hei_robot_vr_real.sh
./run_telegrip.sh
```

Quest 浏览器打开：

```text
https://10.163.141.53:8443
```

接受证书提示并点击 `Start VR`。终端应出现：

```text
VR client connected
VR button ... pressed/released
```

Telegrip 负责端口 `8443`、`8442` 和 `5567`。

## 6. 第三个 WSL 终端：启动控制客户端

先启动客户端，让真机桥能够从 `6559` 获取真实机器人状态。

```bash
source /mnt/e/DevSoft/miniconda3-wsl/etc/profile.d/conda.sh
conda activate hei-rebot-client

cd /mnt/e/code_product/act_hei_robot/software/lerobot-hei-rebot-lift
export PYTHONPATH="$PWD/src"

python -u examples/hei_rebot_lift/teleoperate.py \
  --remote-ip 10.163.141.128 \
  --rerun-ip 127.0.0.1 \
  --rerun-port 9876
```

正常日志：

```text
[HEI VR] robot-state feedback publishing on tcp://*:6559
[HEI Teleoperate] Connecting to robot host=10.163.141.128
Starting HEI ReBot Lift VR teleop loop at 30 fps
Waiting for VR arm qpos messages on tcp://localhost:6558...
```

此时出现 `Waiting` 是正常的，因为第四个终端还没有发布 `6558` 动作。

如果只需要控制、不需要画面，可改用：

```bash
python -u examples/hei_rebot_lift/teleoperate.py \
  --remote-ip 10.163.141.128 \
  --no-rerun
```

## 7. 第四个 WSL 终端：启动 MuJoCo IK 真机桥

```bash
source /mnt/e/DevSoft/miniconda3-wsl/etc/profile.d/conda.sh
conda activate hei-rebot-vr

cd /mnt/e/code_product/act_hei_robot/software/lerobot-hei-rebot-lift/examples/hei_rebot_lift/VR_mujoco_ik
./run_hei_robot_vr_real.sh --enable-real-publish
```

两侧 grip 松开后，应看到：

```text
[HEI VR Real] command bridge ARMED; real pose synchronized
[HEI VR Real] VR=online ... bridge=armed feedback=0.xx ...
```

随后第三个终端的 `Waiting for VR arm qpos` 会停止。

状态解释：

- `VR=online`：Quest 数据正常到达。
- `bridge=armed`：真机动作发布已解锁。
- `feedback=0.xx`：真实机器人反馈新鲜。
- `bridge=locked`：VR 或机器人反馈中断；恢复后松开两侧 grip 重新解锁。

不要使用 `--allow-no-feedback` 控制真机。

## 8. 首次控制方法

1. 日志必须已经显示 `bridge=armed`。
2. 只按住一侧 grip，缓慢移动对应手柄 1～2 cm。
3. grip 按住期间机械臂跟随；松开 grip 后机械臂保持。
4. grip 按住期间，trigger 按下为夹爪张开，松开 trigger 为夹爪闭合。
5. 左 grip + 左摇杆上下控制升降。
6. 右 grip + 右摇杆控制底盘平移；旋转按钮按项目映射使用。
7. 第一次不要测试底盘和升降；先只测试一条机械臂。

异常运动时立即松开 grip，必要时按物理急停。

## 9. 在 Rerun 查看三路相机

Windows Rerun 收到 `teleoperate.py` 数据后，查找以下实体：

```text
observation.images.front
observation.images.left_wrist
observation.images.right_wrist
```

分别对应前置、左腕和右腕相机。若状态有数据但缺少某一路图像，检查机器人 host 的相机日志。反复出现 `Corrupt JPEG data` 说明对应 MJPG 帧存在损坏，应在正式录制前处理相机 USB、线缆、供电或采集参数问题。

### Rerun 是否会保存过程

Rerun 默认实时显示数据，但只保存在 Viewer 内存中。需要保存可回看的 Rerun 记录时，在 Windows PowerShell 启动 Viewer 时增加 `--save`：

```powershell
New-Item -ItemType Directory -Force E:\code_product\act_hei_robot\outputs\rerun | Out-Null

E:\DevSoft\anaconda\envs\lerobot-mujoco\Scripts\rerun.exe `
  --bind 0.0.0.0 `
  --port 9876 `
  --memory-limit 4GB `
  --save E:\code_product\act_hei_robot\outputs\rerun\hei_teleop_test.rrd
```

回放保存的 `.rrd` 文件：

```powershell
E:\DevSoft\anaconda\envs\lerobot-mujoco\Scripts\rerun.exe `
  E:\code_product\act_hei_robot\outputs\rerun\hei_teleop_test.rrd
```

`.rrd` 适合检查相机、动作和状态时间线，不能直接替代 ACT 训练所需的 LeRobotDataset。训练数据必须由 `record.py` 保存。

## 10. 从遥操作切换到数据录制

必须先关闭 `teleoperate.py`，但保留以下程序：

- 机器人 Jetson host：保留；
- Telegrip：保留；
- Windows Rerun：保留；
- MuJoCo IK 真机桥：保留；
- `teleoperate.py`：关闭；
- `record.py`：随后启动。

在第三个终端按 `Ctrl+C`。如果卡住，在另一个 WSL 终端只结束指定程序：

```bash
pkill -f 'examples/hei_rebot_lift/teleoperate.py'
```

确认已经退出：

```bash
pgrep -af 'teleoperate.py'
```

然后启动录制。下面示例录制 5 条，每条最多 120 秒，保存后等待手动复位和空格开始：

```bash
source /mnt/e/DevSoft/miniconda3-wsl/etc/profile.d/conda.sh
conda activate hei-rebot-client

cd /mnt/e/code_product/act_hei_robot/software/lerobot-hei-rebot-lift
export PYTHONPATH="$PWD/src"

python -u examples/hei_rebot_lift/record.py \
  --remote-ip 10.163.141.128 \
  --root /mnt/e/code_product/act_hei_robot/outputs/data/hei_vr_real \
  --repo-id local/hei_vr_real \
  --num-episodes 5 \
  --episode-time-sec 120 \
  --task-description "用双臂完成指定抓取任务" \
  --swap-wrist-cameras \
  --rerun-ip 127.0.0.1 \
  --rerun-port 9876 \
  --no-push-to-hub
```

录制键盘控制：

- 等待状态按一次 `Space`：开始当前 episode。
- 录制状态再按一次 `Space`：提前结束并保存当前 episode。
- 录制状态按 `R`：丢弃当前 episode，回到等待状态；复位后再按 `Space` 重录。
- `Esc`：停止全部录制，丢弃尚未完成的当前 episode，并完成数据集收尾。

每条保存后不会自动开始下一条。程序会进入 `READY` 状态，此时可以自由控制机器人和重新摆放物体，但不会写入训练数据；准备好后再按 `Space` 开始下一条。`--episode-time-sec` 仍是单条数据的最长时间，超过后会自动保存。

继续向同一个本地数据集追加时，保持相同 `--root` 和 `--repo-id`，并增加：

```text
--resume
```

录制时如果不需要 Rerun，可以用 `--no-rerun` 代替 `--rerun-ip/--rerun-port`。

如果检查画面确认左右腕相机字段反了，增加 `--swap-wrist-cameras`。该参数会在显示和写入数据集前交换 `left_wrist` 与 `right_wrist`，不影响前置相机和机器人动作。永久修复应在机器人 Jetson 上重新运行相机绑定向导，正确分配 `/dev/hei_left_wrist_camera` 与 `/dev/hei_right_wrist_camera`。

录制期间，Rerun 显示当前过程；LeRobotDataset 同时把每帧动作、状态和三路相机图像写入 `--root`。录制结束后，终端出现 `Dataset finalized at ...` 才表示数据集完成写盘。

检查数据集是否已产生文件：

```bash
find /mnt/e/code_product/act_hei_robot/outputs/data/hei_vr_real -maxdepth 2 -type f | head -30
```

不要只根据 Rerun 窗口判断录制成功，应确认每个 episode 出现 `saved`，并最终出现 `Dataset finalized`。

## 11. 正确停止顺序

1. 松开两个 grip，摇杆回中。
2. 停止 `teleoperate.py` 或 `record.py`。
3. 停止 MuJoCo IK 真机桥。
4. 停止 Telegrip。
5. 最后停止机器人 host。
6. 按设备规程处理急停和机器人电源。

## 12. 常见故障快速检查

### `No module named lerobot`

进入仓库根目录再设置绝对 `PYTHONPATH`：

```bash
cd /home/jetson/hei-rebot-lift-main/software/lerobot-hei-rebot-lift
export PYTHONPATH="$PWD/src"
```

电脑 WSL 对应路径：

```bash
cd /mnt/e/code_product/act_hei_robot/software/lerobot-hei-rebot-lift
export PYTHONPATH="$PWD/src"
```

### `bash\r: No such file or directory`

```bash
sed -i 's/\r$//' run_telegrip.sh run_hei_robot_vr_real.sh
chmod +x run_telegrip.sh run_hei_robot_vr_real.sh
```

### 一直等待 `6558`

```bash
ss -ltnp | grep ':6558'
```

没有输出表示真机桥没有运行。重新启动第四个终端。

### 真机桥一直 `feedback=waiting`

确认 `teleoperate.py` 或 `record.py` 正在运行，并检查：

```bash
ss -ltnp | grep ':6559'
```

### 真机桥一直 `VR=waiting`

确认 Quest 已点击 `Start VR`，并检查 Telegrip 是否持续收到手柄事件。

### Rerun 报 `R32Float`

不要在 WSL 内生成 Viewer。先在 Windows 启动 Rerun，再给客户端传：

```text
--rerun-ip 127.0.0.1 --rerun-port 9876
```

### 查看当前程序和端口

```bash
ps -ef | grep -E 'telegrip|teleoperate.py|record.py|hei_robot_vr_mujoco_real' | grep -v grep
ss -ltnp | grep -E ':(8442|8443|5567|6558|6559)\b'
```

不要使用 `pkill -f python`，它会误杀其他控制程序。

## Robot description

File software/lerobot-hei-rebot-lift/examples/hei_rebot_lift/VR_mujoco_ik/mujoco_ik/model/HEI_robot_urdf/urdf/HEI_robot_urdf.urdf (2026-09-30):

<?xml version="1.0" encoding="utf-8"?>
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
<robot name="HEI_robot_urdf">
  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
  <mujoco>
    <compiler meshdir="../meshes" strippath="true" discardvisual="false" fusestatic="false" balanceinertia="false" />
  </mujoco>
  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
  <link name="base_footprint" />
  <joint name="base_footprint_joint" type="fixed">
    <origin xyz="0.0577141065 0.0318598182 -0.0427861037" rpy="0 0 -1.5707963268" />
    <parent link="base_footprint" />
    <child link="base_link" />
  </joint>
  <link name="base_link">
    <inertial>
      <origin xyz="0.0318500736747143 0.134408250107984 0.0750627469843922" rpy="0 0 0" />
      <mass value="4.4369989053719" />
      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
    </inertial>
    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
  </link>
  <link name="front_left_wheel_link">
    <inertial>
      <origin xyz="-3.40416028699053E-11 -1.2340328758853E-10 0.00558469119775667" rpy="0 0 0" />
      <mass value="0.00163612324488368" />
      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
    </inertial>
    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
  </link>
  <joint name="front_left_wheel_joint" type="continuous">
    <origin xyz="-0.191724182567996 0.165869894313329 0.119" rpy="1.5707963267949 0 -2.35619449019236" />
    <parent link="base_link" />
    <child link="front_left_wheel_link" />
    <axis xyz="0 0 1" />
  </joint>
  <link name="front_right_wheel_link">
    <inertial>
      <origin xyz="-6.06419775506239E-11 1.12732961854434E-10 0.00558469119775862" rpy="0 0 0" />
      <mass value="0.00163612324488367" />
      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
    </inertial>
    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
  </link>
  <joint name="front_right_wheel_joint" type="continuous">
    <origin xyz="0.25544381896979 0.165869894313322 0.118999999999999" rpy="1.5707963267949 0 2.35619449019222" />
    <parent link="base_link" />
    <child link="front_right_wheel_link" />
    <axis xyz="0 0 1" />
  </joint>
  <link name="rear_left_wheel_link">
    <inertial>
      <origin xyz="-6.06427408289534E-11 1.12737277846442E-10 0.00558469119775673" rpy="0 0 0" />
      <mass value="0.00163612324488369" />
      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
    </inertial>
    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
  </link>
  <joint name="rear_left_wheel_joint" type="continuous">
    <origin xyz="-0.191724182567998 -0.281298107224456 0.119000000000001" rpy="1.5707963267949 0 -0.785398163397458" />
    <parent link="base_link" />
    <child link="rear_left_wheel_link" />
    <axis xyz="0 0 1" />
  </joint>
  <link name="rear_right_wheel_link">
    <inertial>
      <origin xyz="-6.06426853178021E-11 1.12736875390596E-10 0.00558469119775673" rpy="0 0 0" />
      <mass value="0.00163612324488366" />
      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
    </inertial>
    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
  </link>
  <joint name="rear_right_wheel_joint" type="continuous">
    <origin xyz="0.25544381896978 -0.281298107224448 0.118999999999994" rpy="1.57079632679489 0 0.785398163397448" />
    <parent link="base_link" />
    <child link="rear_right_wheel_link" />
    <axis xyz="0 0 1" />
  </joint>
  <link name="lidar_link">
    <inertial>
      <origin xyz="-0.00250804290421403 6.44352150802607E-09 0.0171069574143055" rpy="0 0 0" />
      <mass value="0.0374330181560157" />
      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
    </inertial>
    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
  </link>
  <joint name="lidar_joint" type="fixed">
    <origin xyz="0.0318598182009012 0.152285893544438 0.19" rpy="0 0 1.57079632679488" />
    <parent link="base_link" />
    <child link="lidar_link" />
    <axis xyz="0 0 0" />
  </joint>
  <link name="imu_link">
    <inertial>
      <origin xyz="1.64769300436962E-06 1.64769301196077E-06 0.00499999999999999" rpy="0 0 0" />
      <mass value="0.0357486725877128" />
      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
    </inertial>
    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
  </link>
  <joint name="imu_joint" type="fixed">
    <origin xyz="0.0318598182009012 0.152285893544438 0.0850000000000001" rpy="0 0 1.57079632679488" />
    <parent link="base_link" />
    <child link="imu_link" />
    <axis xyz="0 0 0" />
  </joint>
  <link name="lift_column_link">
    <inertial>
      <origin xyz="-0.00435168272787461 0.469610437281469 0.0952387774941474" rpy="0 0 0" />
      <mass value="2.88486740861506" />
      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
    </inertial>
    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
  </link>
  <joint name="lift_column_joint" type="fixed">
    <origin xyz="0.03186 -0.032214 0.19" rpy="1.5708 0 0" />
    <parent link="base_link" />
    <child link="lift_column_link" />
    <axis xyz="0 0 0" />
  </joint>
  <link name="lift_carriage_link">
    <inertial>
      <origin xyz="0.0756204015645276 0.00224613261704043 0.0109761810755997" rpy="0 0 0" />
      <mass value="1.54411126706519" />
      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
    </inertial>
    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
  </link>
  <joint name="lift_joint" type="prismatic">
    <origin xyz="0 0.87 0.0255" rpy="1.5708 1.5708 3.1416" />
    <parent link="lift_column_link" />
    <child link="lift_carriage_link" />
    <axis xyz="0 0 1" />
    <limit lower="-0.8" upper="0" effort="0" velocity="0" />
  </joint>
  <link name="a_right_base_link">
    <inertial>
      <origin xyz="6.56684538122981E-06 -2.07448643286812E-05 0.0349662004906963" rpy="0 0 0" />
      <mass value="0.402787177092637" />
      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
    </inertial>
    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
  </link>
  <joint name="a_right_base_mount" type="fixed">
    <origin xyz="0.096 -0.23 -0.056" rpy="0 0 0" />
    <parent link="lift_carriage_link" />
    <child link="a_right_base_link" />
    <axis xyz="0 0 0" />
  </joint>
  <link name="a_right_link1">
    <inertial>
      <origin xyz="9.64709983311621E-05 -0.000526979727385357 0.0539265681374985" rpy="0 0 0" />
      <mass value="0.0833530095742827" />
      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
    </inertial>
    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
  </link>
  <joint name="a_right_joint1" type="revolute">
    <origin xyz="0 0 0.0365" rpy="0 0 0" />
    <parent link="a_right_base_link" />
    <child link="a_right_link1" />
    <axis xyz="0 0 1" />
    <limit lower="-0.3" upper="1.5" effort="27" velocity="50" />
  </joint>
  <link name="a_right_link2">
    <inertial>
      <origin xyz="-0.132246385887772 -0.00387496570683443 0.00306722076781929" rpy="0 0 0" />
      <mass value="0.705349739064212" />
      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
    </inertial>
    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
  </link>
  <joint name="a_right_joint2" type="revolute">
    <origin xyz="0.02 0.004675 0.0897" rpy="0 0 0" />
    <parent link="a_right_link1" />
    <child link="a_right_link2" />
    <axis xyz="0 -1 0" />
    <limit lower="-3.14" upper="0" effort="27" velocity="50" />
  </joint>
  <link name="a_right_link3">
    <inertial>
      <origin xyz="0.123498314020929 -0.00389750455678084 0.0542348768186509" rpy="0 0 0" />
      <mass value="0.52520909407384" />
      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
    </inertial>
    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
  </link>
  <joint name="a_right_joint3" type="revolute">
    <origin xyz="-0.264 0 0" rpy="0 0 0" />
    <parent link="a_right_link2" />
    <child link="a_right_link3" />
    <axis xyz="0 1 0" />
    <limit lower="-3.14" upper="0" effort="27" velocity="50" />
  </joint>
  <link name="a_right_link4">
    <inertial>
      <origin xyz="0.0635507417115015 -0.00290463621996007 0.0533154391743242" rpy="0 0 0" />
      <mass value="0.182914560739641" />
      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
    </inertial>
    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
  </link>
  <joint name="a_right_joint4" type="revolute">
    <origin xyz="0.2426 -0.0019048 0.054146" rpy="0 0 0" />
    <parent link="a_right_link3" />
    <child link="a_right_link4" />
    <axis xyz="0 1 0" />
    <limit lower="-1.4" upper="1.57" effort="7" velocity="200" />
  </joint>
  <link name="a_right_link5">
    <inertial>
      <origin xyz="-0.00208877175564695 0.000146333125480402 -0.0617707400113767" rpy="0 0 0" />
      <mass value="0.134196923597164" />
      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
    </inertial>
    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
  </link>
  <joint name="a_right_joint5" type="revolute">
    <origin xyz="0.078308 -0.0029167 0.062583" rpy="0 0 0" />
    <parent link="a_right_link4" />
    <child link="a_right_link5" />
    <axis xyz="0 0 -1" />
    <limit lower="-1.57" upper="1.57" effort="7" velocity="200" />
  </joint>
  <link name="a_right_link6">
    <inertial>
      <origin xyz="0.0655269830862821 6.98989603294398E-05 -0.000143922297662025" rpy="0 0 0" />
      <mass value="0.190049959858017" />
      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
    </inertial>
    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
  </link>
  <joint name="a_right_joint6" type="revolute">
    <origin xyz="0.00046248 0.0001465 -0.065083" rpy="0 0 0" />
    <parent link="a_right_link5" />
    <child link="a_right_link6" />
    <axis xyz="1 0 0" />
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

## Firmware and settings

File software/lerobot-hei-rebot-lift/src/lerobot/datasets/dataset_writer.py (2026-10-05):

#!/usr/bin/env python

# Copyright 2024 The HuggingFace Inc. team. All rights reserved.
#
# Licensed under the Apache License, Version 2.0 (the "License");
# you may not use this file except in compliance with the License.
# You may obtain a copy of the License at
#
#     http://www.apache.org/licenses/LICENSE-2.0
#
# Unless required by applicable law or agreed to in writing, software
# distributed under the License is distributed on an "AS IS" BASIS,
# WITHOUT WARRANTIES OR CONDITIONS OF ANY KIND, either express or implied.
# See the License for the specific language governing permissions and
# limitations under the License.
"""Private writer component for LeRobotDataset. Handles sequential recording (episode buffer, ParquetWriter, image writer, video encoding)."""

from __future__ import annotations

import concurrent.futures
import contextlib
import logging
import shutil
import tempfile
from pathlib import Path

import datasets
import numpy as np
import pandas as pd
import PIL.Image
import pyarrow.parquet as pq
import torch

from lerobot.configs import VideoEncoderConfig, camera_encoder_defaults

from .compute_stats import compute_episode_stats
from .dataset_metadata import LeRobotDatasetMetadata
from .feature_utils import (
    get_hf_features_from_features,
    validate_episode_buffer,
    validate_frame,
)
from .image_writer import AsyncImageWriter, write_image
from .io_utils import (
    embed_images,
    get_file_size_in_mb,
    load_episodes,
    write_info,
)
from .utils import (
    DEFAULT_EPISODES_PATH,
    DEFAULT_IMAGE_PATH,
    update_chunk_file_indices,
)
from .video_utils import (
    StreamingVideoEncoder,
    concatenate_video_files,
    encode_video_frames,
    get_video_duration_in_s,
)

logger = logging.getLogger(__name__)


def _encode_video_worker(
    video_key: str,
    episode_index: int,
    root: Path,
    fps: int,
    camera_encoder: VideoEncoderConfig | None = None,
    encoder_threads: int | None = None,
) -> Path:
    temp_path = Path(tempfile.mkdtemp(dir=root)) / f"{video_key}_{episode_index:03d}.mp4"
    fpath = DEFAULT_IMAGE_PATH.format(image_key=video_key, episode_index=episode_index, frame_index=0)
    img_dir = (root / fpath).parent
    encode_video_frames(
        img_dir,
        temp_path,
        fps,
        camera_encoder=camera_encoder,
        encoder_threads=encoder_threads,
        overwrite=True,
    )
    shutil.rmtree(img_dir)
    return temp_path


class DatasetWriter:
    """Encapsulates write-side state and methods for LeRobotDataset.

    Owns: episode_buffer, image_writer, _pq_writer (ParquetWriter), _latest_episode,
    _current_file_start_frame, _streaming_encoder, _episodes_since_last_encoding, _recorded_frames.
    """

    def __init__(
        self,
        meta: LeRobotDatasetMetadata,
        root: Path,
        camera_encoder: VideoEncoderConfig | None,
        encoder_threads: int | None,
        batch_encoding_size: int,
        streaming_encoder: StreamingVideoEncoder | None = None,
        initial_frames: int = 0,
    ):
        """Initialize the writer with metadata, codec, and encoder config.

        Args:
            meta: Dataset metadata instance (used for feature schema, chunk
                settings, and episode persistence).
            root: Local dataset root directory.
            camera_encoder: Video encoder settings applied to all cameras.
                ``None`` uses :func:`~lerobot.configs.camera_encoder_defaults`.
            encoder_threads: Number of encoder threads (global). ``None``
                lets the codec decide.
            batch_encoding_size: Number of episodes to accumulate before
                batch-encoding videos.
            streaming_encoder: Optional pre-built :class:`StreamingVideoEncoder`
                for real-time encoding. ``None`` disables streaming mode.
            initial_frames: Starting frame count (non-zero when resuming).
        """
        self._meta = meta
        self._root = root
        self._camera_encoder = camera_encoder or camera_encoder_defaults()
        self._encoder_threads = encoder_threads
        self._batch_encoding_size = batch_encoding_size
        self._streaming_encoder = streaming_encoder

        # Writer state
        self.image_writer: AsyncImageWriter | None = None
        self.episode_buffer: dict = self._create_episode_buffer()
        self._pq_writer: pq.ParquetWriter | None = None
        self._latest_episode: dict | None = None
        self._current_file_start_frame: int | None = None
        self._episodes_since_last_encoding: int = 0
        self._recorded_frames: int = initial_frames
        self._finalized = False

    def _create_episode_buffer(self, episode_index: int | None = None) -> dict:
        current_ep_idx = self._meta.total_episodes if episode_index is None else episode_index
        ep_buffer = {}
        ep_buffer["size"] = 0
        ep_buffer["task"] = []
        for key in self._meta.features:
            ep_buffer[key] = current_ep_idx if key == "episode_index" else []
        return ep_buffer

    def _get_image_file_path(self, episode_index: int, image_key: str, frame_index: int) -> Path:
        fpath = DEFAULT_IMAGE_PATH.format(
            image_key=image_key, episode_index=episode_index, frame_index=frame_index
        )
        return self._root / fpath

    def _get_image_file_dir(self, episode_index: int, image_key: str) -> Path:
        return self._get_image_file_path(episode_index, image_key, frame_index=0).parent

    def _save_image(
        self, image: torch.Tensor | np.ndarray | PIL.Image.Image, fpath: Path, compress_level: int = 1
    ) -> None:
        if self.image_writer is None:
            if isinstance(image, torch.Tensor):
                image = image.cpu().numpy()
            write_image(image, fpath, compress_level=compress_level)
        else:
            self.image_writer.save_image(image=image, fpath=fpath, compress_level=compress_level)

    def add_frame(self, frame: dict) -> None:
        """
        Add a single frame to the current episode buffer.

        Apart from images written to a temporary directory, nothing is written to disk
        until ``save_episode()`` is called.

        The caller must provide all user-defined features plus ``"task"``, and must
        not provide ``"timestamp"`` or ``"frame_index"``; those are computed
        automatically.
        """
        # Convert torch to numpy if needed
        for name in frame:
            if isinstance(frame[name], torch.Tensor):
                frame[name] = frame[name].numpy()

        validate_frame(frame, self._meta.features)

        if self.episode_buffer is None:
            self.episode_buffer = self._create_episode_buffer()
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

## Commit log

2026-09-30 适应windows
2026-09-30 Add MuJoCo simulation data workflow
    [HEI_robot_urdf.urdf, front_camera_link.STL, left_wrist_camera_link.STL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]
2026-10-01 Improve VR recording workflow and camera mapping
2026-10-05 Fix video frame cleanup and restore VR recording
    [dataset_writer.py]
